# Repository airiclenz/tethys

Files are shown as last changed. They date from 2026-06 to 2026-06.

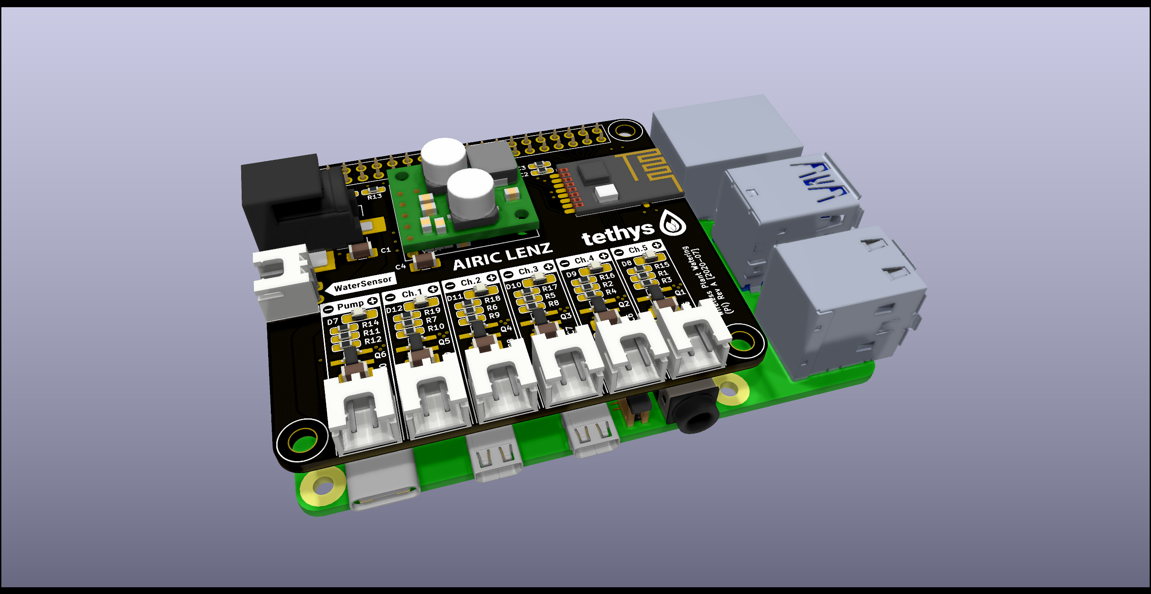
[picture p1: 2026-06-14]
graphics/renders/WaterPlant Pi with PaspPi Render.png

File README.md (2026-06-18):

<div align="center">
Tethys logo

**A self-hosted, multi-channel automatic plant-watering system.**
</div>

Battery-powered wireless soil-moisture sensors report to a Raspberry Pi master
over a 2.4 GHz nRF24 radio link. The master decides when to water, drives the
pumps/valves, and serves a real-time web dashboard — all on your own LAN, no
cloud.

## Part 1 — What Tethys is and how to use it

### The big picture

Tethys has two kinds of hardware:

1. **Sensor nodes** (one per plant/pot, up to 5) — a battery-powered ATtiny84
   board with a capacitive soil-moisture probe and an nRF24L01+ radio. Each node
   sleeps almost all the time, wakes on a configurable interval, measures soil
   moisture and battery voltage, transmits a reading, and goes back to sleep.
   Designed to run for months on a single charge (~9 µA while sleeping).

2. **The master** — a Raspberry Pi with a custom HAT carrying the matching
   nRF24L01+ radio plus pump/valve driver outputs. The master listens for sensor
   readings, stores them, and when a channel's soil drops below its trigger
   threshold it runs that channel's pump (or opens its valve) for a configured
   duration. It also serves the web UI you use to configure and monitor
   everything.

```
   ┌─────────────┐   nRF24 2.4GHz      ┌──────────────────────────────────┐
   │ Sensor node │  (250kbps, 8-byte   │         Raspberry Pi master      │
   │  ATtiny84   │   versioned frames) │                                  │
   │  + moisture │ ◄──── reading ────► │  core daemon ─► pump/valve GPIO  │
   │  + nRF24    │      config ◄────   │              │                   │
   │  (battery)  │                     │  Django API (SQLite) ◄─► web UI  │
   └─────────────┘                     └──────────────┬───────────────────┘
        × up to 5                                     │  HTTP / WebSocket
                                                      ▼
                                              Your browser / phone
```

Each **channel** (1..5) pairs one sensor node with one pump or valve output.
A channel knows its soil-moisture trigger %, its pump run duration, and how
often its sensor should measure.

### Repository layout

```
tethys/
├── code/
│   ├── master/            # Everything that runs on the Raspberry Pi
│   │   ├── core/          # The watering daemon (radio + pump control + action engine)
│   │   ├── api/           # Django REST API (the system's database + state)
│   │   ├── web/           # Django + Channels dashboard (browser UI)
│   │   ├── camera/        # Optional on-demand webcam snapshot service (USB/V4L2)
│   │   ├── watchdog/      # Daily service-restart / log-vacuum job
│   │   ├── globals/       # Shared config + git-ignored secrets
│   │   └── install/       # install.sh, systemd units, nginx configs
│   └── sensor/            # Arduino/PlatformIO firmware for the sensor nodes (the "wpw" project)
├── hardware/              # KiCad schematics + Gerbers for the Pi HAT and the sensor PCB
├── graphics/              # Logos, hardware labels, web-UI assets, renders
└── docs/                  # Audits, protocol review, hardening notes, handoffs
```

### Hardware

**Master — Raspberry Pi + "WaterPlant Pi" HAT** (`hardware/rpi hat/`).
GPIO assignments live in [`code/master/core/hardware.py`](code/master/core/hardware.py):

| Function | BCM pin(s) | Notes |
|---|---|---|
| Channel outputs | `16, 19, 20, 26, 21`  | One per channel; `CHANNEL_COUNT = 5` |
| Shared pump pin | `6` | Energised together with a channel in **valve** mode |
| Water-level sensor| `4` | |
| nRF24 CE / CSN / IRQ | `22 / 0 / 17` | SPI radio |
| Status LED / Fan  | `14 / 15` | |

A channel of type **pump** drives its own pin directly. A channel of type
**valve** drives its pin *and* the shared `PUMP` pin (one pump pushing water
through whichever valves are open); the pump pin is reference-counted so it
only drops once the last valve closes.

**Sensor node — "Sensor" PCB** (`hardware/sensor/`), firmware in `code/sensor/`:

- **MCU:** ATmega/ATtiny84 @ 8 MHz (PlatformIO `TX` build), deep-sleep
  `SLEEP_MODE_PWR_DOWN`, woken by the 8-second watchdog timer.
- **Radio:** nRF24L01+ on CE=8 / CSN=9, 250 kbps, CRC-8, auto-ACK.
- **Moisture:** capacitive probe excited by a ~500 kHz square wave (Timer0 on
  `PB2`), read on ADC `PA3`; calibration min/max stored in EEPROM.
- **Battery:** monitored on `A7` against the internal 1.1 V reference; below
  **3.2 V** the node sends a battery-alert frame instead of a normal reading.

### Install (on the Raspberry Pi)

```bash
sudo apt install git -y
git clone https://github.com/airiclenz/tethys.git tethys
cd tethys/code/master/install
./install.sh
```

The installer updates the OS, creates a Python venv, installs Redis + nginx,
runs the Django migrations, registers the systemd services, enables SPI, and
**reboots** (re-run `./install.sh --rebooted=true` afterward if you decline the
auto-reboot). On first run it generates a random **API key** into the
git-ignored `code/master/globals/secrets.py` and **prints it** — copy it.

Useful flags:
- `--debug=true` — developer install (also installs the TypeScript toolchain).
- `--allowed-hosts=tethys.<tailnet>.ts.net` — extra `ALLOWED_HOSTS` for remote
  (VPN) access. Alternatively (and preferred per-install), list the name in the
  git-ignored `code/master/globals/allowed_hosts.py` (copy `allowed_hosts.example.py`)
  — no reinstall needed, just restart the services. See
  [`docs/remote-access-hardening.md`](docs/remote-access-hardening.md).

After it's up: open `http://<pi-host>/` in a browser → **Settings** (top menu) →
paste the API key → Save. The key gates **every** request (reads included; only
the CORS `OPTIONS` preflight is exempt), so the dashboard stays blank until it's
set. If a page can't authenticate (missing or wrong key), a warning banner
appears under the header with a link straight to Settings.

### Daily use

- **Sensor Readings page** (`/`) — per-channel reading history: two trend charts
  (moisture % and battery voltage over time) sit above a sortable table of the
  individual readings.
- **Channels page** (`/channels/`) — live moisture %, battery, last action per
  channel; enable a channel, set its nickname, type (pump/valve), pump duration,
  and the moisture trigger %; manually test a pump.
- **Schedules page** (`/schedules/`) — define **silent phases** (quiet hours):
  weekday + start time + duration windows during which *all* automatic watering
  is suppressed (e.g. overnight). The header shows a sleep icon while a silent
  phase is active.
- **Webcam page** (`/webcam/`) — *optional* live view from a USB camera. Off by
  default; flip **Enable** to refresh a snapshot every few seconds. Live-view
  only — nothing is recorded, and the camera releases automatically when you
  leave the tab or after an idle timeout. See *Webcam* below.
- **Order 66** (top menu) — recovery action for when a service or the Pi itself
  gets wedged: confirm the popup and the Pi performs a graceful reboot (back in
  ~1 minute). Gated by the API key, like pump control.
- The dashboard updates live over a WebSocket; no manual refresh needed.

### Webcam (optional)

Tethys can show a live webcam view on its own **Webcam** tab — handy for checking
on plants — but it ships **off** and only captures **on demand**:

- **USB camera (V4L2).** Plug in any UVC webcam; the service grabs JPEG snapshots
  with `v4l2-ctl` (no extra Python dependency). A Pi Camera Module (CSI) is not
  wired up yet — the capture code keeps a seam (`camera/captureBackend.py`) for
  adding it as one new class.
- **Snapshot-only, nothing recorded.** The tab fetches a fresh JPEG every few
  seconds (an authenticated `fetch`, gated by the same API key as everything
  else). There is no video stream and no storage — purely a live view.
- **Pick the size, view it full-screen.** A dropdown lists the resolutions the
  camera itself reports (so it isn't tied to one model), and the live frame can be
  expanded to fill the screen — both handy on a phone. The choice is per-session
  only; nothing is saved.
- **Focus & zoom sliders.** A plant sits at a fixed distance, so autofocus just
  hunts. The tab offers focus and zoom as sliders whose ranges are read from the
  camera itself — and a slider is disabled when the camera doesn't support that
  control. Setting focus pins it (no more hunting). Your pick is remembered in the
  browser; `CAPTURE_FOCUS` / `CAPTURE_ZOOM` in `camera/config.py` set the
  defaults a fresh browser starts from.
- **Fail-closed + auto-off.** The service boots disabled (a snapshot while off
  returns `409`). It auto-releases the camera after a short idle window and
  enforces a hard maximum on-time, mirroring the pump's auto-off safety — so the
  camera can never be left on by accident.
- **Least privilege.** `tethys-camera` runs as the normal app user (no root,
  unlike `tethys-core`), with only the `video` group added so it can open the
  `root:video` `/dev/video*` nodes. The installer adds the user to that group and
  installs `v4l-utils`.

### Updating / operating

From `code/master/install/`:
- `./installServices.sh` — re-deploy the systemd services from the current code.
- `./services-restart.sh`, `./services-stop.sh`, `./services-clearLogs.sh`.
- `./deploy-static.sh` — rebuild the frontend TypeScript and publish it to nginx.

The six services: `tethys-core`, `tethys-api`, `tethys-web`, `daphne`,
`tethys-watchdog` (restarts core+api+camera nightly at 01:00 and vacuums the
journal), and `tethys-camera` (the optional on-demand webcam, off by default).

### Firmware (sensor nodes)

Built with [PlatformIO](https://platformio.org/) from `code/sensor/`. Before
building, set the node identity in [`code/sensor/include/wpw_Config.h`](code/sensor/include/wpw_Config.h):
`SENSOR_NUMBER` (1–5). Flash with:

```bash
cd code/sensor
pio run -t program -e tethys-sensor     # via an AVR ISP programmer
```

> ⚠️ **The master and every sensor must be flashed together.** The wire format
> is versioned and fixed-size; a node on mismatched firmware fails the version
> check and goes silent (cleanly — it never corrupts data). See the
> *Known limitations / coordinated flash* note in [`CHANGELOG.md`](CHANGELOG.md).

### Sensor node LED — calibration & status blinks

A sensor node has no screen; its single onboard LED is how it talks to you.
Patterns are produced by `DoSimpleBlink(onMs, offMs)` and `DoSoftPulse(ms)`
([`code/sensor/src/wpw_Blinker.cpp`](code/sensor/src/wpw_Blinker.cpp); the soft
pulse is a software-PWM glow, since the LED pin has no free hardware PWM).

**How calibration works.** Calibration maps the probe's raw reading onto a
0–100 % moisture scale, and it is **two-point**: the node captures one reading in
a *wet* condition and one in a *dry* condition, then stores the lower value as
`MinimumValue` (wettest) and the higher as `MaximumValue` (driest) in EEPROM
(`Calibrate()` in [`code/sensor/src/wpw_Sensor.cpp`](code/sensor/src/wpw_Sensor.cpp)).
Later readings become `100 − map(raw, min, max, 0, 100)` %.

1. Trigger it from the web UI — set the channel's **calibrate** flag
   (`sensorTriggerCalibration`), then **power-cycle or reset the node**.
   Calibration runs only as part of the **boot-time** config exchange (the full
   `GETCONFIG` in `setup()`) — *not* on a normal measurement wake. A running node
   re-pulls its config periodically (see *Periodic config pull* below), but those
   pulls are deliberately **settings-only**: they carry measure-frequency /
   TX-power but never the calibration trigger, so they can't run calibration
   mid-life. The master delivers the trigger once and immediately clears the flag
   (`core/radio.py`), so if you set the flag while the node is already running,
   nothing happens until you reset it. (This is the usual reason a calibration
   "didn't start".)
2. The node then takes **two** measurements, each announced by the *calibration
   countdown* below (slow blinks → fast blinks → one long blink → it measures
   while the LED is off). Put the probe in one condition for the first capture
   and the other condition for the second.
3. **Order doesn't matter** — the firmware sorts the two readings into min/max.
   What matters is that the two conditions are genuinely different: if the two
   readings are too close, the calibration is **rejected** and the previous
   values are kept (signalled by the long 2 s blink).

**First reading after boot.** On every boot — including right after calibration —
the node waits ~1 minute (`STARTUP_SETTLE_SECONDS`, default 60, in
[`wpw_Config.h`](code/sensor/include/wpw_Config.h)) before taking and transmitting
its first reading. It *sleeps* through the wait (you'll see the heartbeat flash
each ~9 s), so it costs almost no power. Put the probe in its final monitoring
position before this window ends — the first reported value reflects wherever the
probe is at that moment, **not** the calibration captures.

**Periodic config pull.** A running node re-pulls its config so web-UI changes
(measure frequency, transmission power) reach it without a power-cycle. The cadence
is `PULL_CONFIG_CYCLE_SECONDS` in [`wpw_Config.h`](code/sensor/include/wpw_Config.h)
(default `3600` = 1 h; **`0` disables it** for maximum battery saving). To stay
gentle on the battery the pull **rides an existing measurement wake** — the radio
is already powered up, so it adds no extra power-up, and the master answers from
its warm `ConfigCache` so the listen window is usually a few milliseconds. The pull
therefore happens on the first measurement at/after the cycle has elapsed since the
last pull. These pulls are **silent** (no LED) and **settings-only** — they never
carry or clear the calibration trigger (calibration stays boot-only; see above).

The patterns, all on the sensor (TX) node LED:

| Event | Blink pattern | Meaning |
|---|---|---|
| **Power-on / node ID** | `N` slow blinks (150 ms on, 300 ms off), where `N` = `SENSOR_NUMBER` | Node booted and is powered; the count identifies which node it is (1–5). |
| **Config received** | a soft ~2 s glow (brightness ramps up then down) | The master answered the config request (at boot) and the settings were applied. |
| **No master reply** | two short flashes (15 ms) | Config request timed out (no answer within 500 ms); the node falls back to the settings stored in EEPROM. |
| **Config rejected** | three short flashes (15 ms) | The master replied but the frame failed the protocol-version / type check. |
| **Settings saved** | accelerating ramp — 150 → 100 → 75 → 50 → 25 → 15 ms — then one long 300 ms flash (ramps *up* to a strong finish) | New settings differed from EEPROM and were written. |
| **Settings unchanged** | decelerating ramp — 15 → 25 → 50 → 75 → 100 → 150 ms — fading out with no final flash (the mirror of *saved*) | Config was checked but nothing changed, so nothing was written. |
| **Heartbeat** | one very short flash (5 ms) each wake (~every 9 s) | Normal sleep/measure loop tick — the node is alive. |
| **Transmit failed** | four short flashes (15 ms) | The radio send failed; the node backs off (~15 min) before retrying. Part of the short-flash radio-error family, counted: 2 = no reply, 3 = bad frame, 4 = send failed (a *successful* config exchange is the soft glow above instead). |
| **Calibration countdown** | 10 slow blinks (300 ms) → 20 fast blinks (100 ms) → one long blink (1 s) → LED off while it measures | Counts down to a calibration capture. Runs **twice**, once per measurement point. |
| **Calibration rejected** | one very long flash (2 s) | The two calibration readings were too close together; calibration was discarded and the previous values kept. |

---

## Part 2 — Orientation for a contributor or coding agent

This half is the lightweight `CLAUDE.md`: the runtime topology, the invariants
that are easy to break, and where to look. Read it before changing anything on
the master.

### Process & port map

Everything runs on the Pi as systemd services (units in
`code/master/install/assets/*.service`, nginx in `*.nginx`):

| Service | Process | Binds | Reached via |
|---|---|---|---|
| `tethys-core` | `core/tethys_core.py` (asyncio) | — (GPIO/radio) | n/a |
| `tethys-api` | gunicorn → `tethys_api.wsgi` | `localhost:5001` | nginx **:5000** |
| `tethys-web` | gunicorn → `tethys_web.wsgi` | `localhost:8000` | nginx **:80** `/` |
| `daphne` | ASGI → `tethys_web.asgi` | `0.0.0.0:8001` | nginx **:80** `/ws/`|
| `tethys-watchdog` | `watchdog/tethys_watchdog.py` | — | nightly restart |
| `tethys-camera` | `camera/tethys_camera.py` (stdlib HTTP) | `127.0.0.1:8002` | nginx **:80** `/camera/` |
| redis-server | Channels layer for daphne | `localhost:6379` | — |

**The API is the single source of truth.** Both the core daemon and the web
backend treat it as the database boundary and reach it at `http://localhost:5000/api/`
(nginx → gunicorn:5001). It is Django REST Framework over **SQLite**
(`api/db.sqlite3`).

### Data flow (one reading → one watering)

1. A sensor wakes, measures, and transmits a 7-byte frame on its pipe.
2. `core/radio.py` (`checkRadioInbox` → `handlePayload`) drains the RX FIFO,
   validates each frame via `core/protocol.py`, and `POST`s the reading to
   `sensorData/`. On success it sets that channel's flag in
   `core/config.py::FlagHandler.channelFlags`.
3. `core/actionEngine.py::handleActions` (called each core-loop pass) checks the
   **silent phase** first (fail-closed — see below), then for each flagged
   channel pulls `channelSummary/<n>` and, if `moisture <= trigger` and the
   channel is enabled, calls `pumpController.run_pump(...)`.
4. `core/pumpController.py` energises the line, arms a `threading.Timer`
   auto-off, and on completion writes an `actionLog/` entry — all non-blocking,
   so the radio keeps listening while a pump runs.
5. The web UI sees the change: `web/tethys_web/jobs.py` polls the API every 10 s
   (`/lastUpdate/`, `/channelSummary/`, `/schedule/`, `/silentPhaseStatus/`) and,
   on a change, broadcasts to all browsers over the `/ws/tethys/` WebSocket
   (`web/tethys_web/consumers.py`).

A **manual *Test Channel* tap** uses the same hardware path, not a separate one:
the API enqueues a `ManualCommand` (it never drives GPIO), the core drains it each
loop pass and runs it through the same `pumpController` (rejecting an activate when
another channel is already running), and writes the outcome back for the UI to
poll. This is what keeps the one-channel power limit holding for manual control —
see *Invariants* below.

When a sensor asks for its config (`GETCONFIG`), the master answers from an
in-memory `ConfigCache` (warmed out-of-band by `Radio.refreshConfigCache`), never
with a blocking HTTP call inside the sensor's short listen window. A running node's
periodic, settings-only pull (`GETCONFIG_PERIODIC`) is answered the same way but
with the calibration trigger stripped and never cleared.

### Invariants — break these and something physical or silent goes wrong

- **Pump safety.** Every "pump on" is clamped to `MAX_PUMP_SECONDS = 300` and has
  a guaranteed off (timer + `try/finally`). The controller drives all lines LOW
  on construction (fail-safe boot) and on `SIGTERM`/`atexit`. Never reintroduce a
  watering path that bypasses `pumpController`. `make_controller()` is the *only*
  place `lgpio` is bound; all hardware goes through the `GpioAdapter` seam so the
  logic is testable without a Pi.
- **One channel at a time (power limit).** `pumpController` is the *single owner*
  of the watering GPIO. Both automatic watering and the web UI's manual *Test
  Channel* taps go through it — the latter via the `ManualCommand` queue the core
  drains each loop pass — so its `max_concurrent = 1` guard holds the invariant
  that **at most one channel (plus the shared pump pin) is ever energised**, which
  protects the power supply. A manual activate that arrives while another channel
  is running is *rejected*, not run. The API process never drives GPIO itself.
- **Silent phase is fail-closed.** If the API is unreachable, `isInSilentPhase()`
  returns `None` and `actionEngine` **skips watering** for that pass — it must
  never water on unknown state. The window math lives in
  `api/tethys_api/silentphase.py` (stdlib-only, unit-tested independently of
  Django).
- **Timezones.** `globals/config.py::TIME_ZONE` (`Europe/Stockholm`) is the
  single deployment/display zone, shared by `core` and `web`. The **Django API
  deliberately keeps `TIME_ZONE = 'UTC'` as its storage zone** — schedule start
  times are wall-clock times-of-day stored on a placeholder date; the deployment
  zone is applied only at silent-phase evaluation. Don't "fix" the API to local
  time. (See the silent-phase fixes in `CHANGELOG.md` for why.)
- **Wire protocol is versioned and fixed-size.** `core/protocol.py` and
  `sensor/include/wpw_RXTX.h` / `wpw_Config.h` must stay byte-for-byte in sync:
  `PROTOCOL_VERSION = 1`, `PAYLOAD_SIZE = 8`, structs `<BBBf>` (sensor→master, 7 B)
  and `<BBHB?>` (master→sensor, 6 B). Bump `PROTOCOL_VERSION` on *any* layout
  change — and re-flash everything (no backward compat). Adding a new *message
  type* (the type byte, e.g. `DATATYPE_CMD_GETCONFIG_PERIODIC = 8`) is **not** a
  layout change, so it does not bump the version; keep the type constants in sync
  on both ends. An un-updated peer ignores an unknown type (the sensor's periodic
  pull just times out and retries), so mixed versions degrade gracefully.
- **Pipe 0 is reserved.** Channels map 1:1 onto nRF24 reading pipes 1..N; pipe 0
  is the ACK/writing address. This caps the link at 5 sensors. See
  `protocol.pipe_for_channel`.
- **`CHANNEL_COUNT` is the single source of truth** (`= len(Pins.CHANNELS) = 5`).
  The DB/radio reference 6 channels historically; a 6th needs a physical GPIO pin
  first. Don't hardcode channel counts.
- **Secrets.** `globals/secrets.py` (git-ignored) holds `TETHYS_API_KEY`,
  `API_SECRET_KEY`, `WEB_SECRET_KEY`, and is read by *both* the Django apps and
  the non-Django core. Template: `globals/secrets.example.py`. Every API request
  needs `X-API-Key` (reads included; only CORS `OPTIONS` is exempt) — see
  `api/tethys_api/permissions.py::ApiKeyRequired`.

### Auth posture

A single shared API key gates **all** requests, compared constant-time,
fail-closed. The core (`apiInterface.py`, `radio.py`) and the web backend
(`jobs.py`, `tools.py`) send it server-side; the browser stores it in
`localStorage` and `common.ts` injects it into every fetch. Transport is plain
HTTP on the LAN — for remote access, front it with a VPN overlay (Tailscale/
WireGuard), not an open port. See [`docs/remote-access-hardening.md`](docs/remote-access-hardening.md).

### Data model (Django, `api/tethys_api/models.py`)

- **Channel** (`number` PK) — `enabled`, `nickName`, `channelType` (pump/valve),
  `actionTriggerPercent`, `pumpDurationSeconds`, `sensorMeasureFrequencyMinutes`,
  `sensorTriggerCalibration`, `sensorTransmissionPowerLevel`.
- **SensorData** — `channel` FK, `moisturePercent`, `batteryVoltage`, `timestamp`.
- **ActionLog** — `channel` FK, `actionType`, `startTime`, `endTime`.
- **Schedule** — `weekday`, `scheduleType` (`silent`), `startTime` (UTC wall-clock),
  `durationMinutes`, `enabled`.
- **ManualCommand** — `channel` FK, `action` (activate/deactivate), `status`,
  `message`, `requestedAt`, `processedAt`. The web UI enqueues a manual *Test
  Channel* tap here; the core drains it through `pumpController` (the API never
  drives GPIO) and reports the outcome back for the UI to poll.
- Lookup tables: `ChannelType`, `ActionType`, `ScheduleType`, `TransmissionPowerLevel`.
- `channelSummary/<n>` is the denormalized read both the core and UI consume
  (channel config + latest sensor reading + counts).

### Tests

**Backend (core + API)** — pure Python, no Pi/hardware needed:

```bash
cd code/master
pip install -r install/python-requirements-dev.txt   # pytest, dev-only
pytest                                                # pytest.ini sets paths
```

Covers the parts that gate physical action or silent failure: `core/tests/`
(pump controller, GPIO adapter, protocol framing, action engine, manual-command
queue) and `api/tethys_api/tests/` (API-key permission, silent-phase window math,
`LAST_DATA_UPDATE` wiring, manual-command lifecycle). All run without `lgpio`/`pyrf24`/a Pi, thanks to the
GPIO and protocol seams. **Add tests behind those seams when you touch the
watering, radio-framing, or silent-phase paths.**

The camera service has its own pure-Python suite (`camera/tests/`: the
fail-closed snapshot gate, idle / max-on auto-off, and the X-API-Key check, via
`FakeSnapshotBackend`). It is not in the default `testpaths`, so run it
explicitly: `pytest camera/tests`.

**Web UI (Playwright)** — browser-driven regression tests for the channels UI:

```bash
cd code/master/web
pip install -r requirements-dev.txt
playwright install --with-deps chromium   # downloads Chromium + apt libs (needs sudo)
pytest
```

These drive a headless Chromium against a throwaway Django live server, exercising
the real compiled JavaScript (`conftest.py` compiles `static/ts` → `static/js`
first), so they catch DOM/click-handler bugs the Python suites can't. See
[`web/tests/README.md`](code/master/web/tests/README.md) for what's covered and how
it works. A developer install (`install.sh --debug=true`) installs all of the above
automatically.

### Frontend build

TypeScript sources in `web/static/ts/` compile to `web/static/js/` via
`compile.sh` (`tsc`) / `compileAutomatically.sh` (watch). The build is strict
(`strict: true` in `tsconfig.json`) and `tsc -p tsconfig.json` compiles cleanly.
Use `install/deploy-static.sh` to compile + publish to the nginx static dir. The
compiled `web/static/js/` is git-ignored — it is rebuilt from the `.ts` sources on
deploy and before the UI tests, so the TypeScript is the single source of truth.

> ⚠️ **Editing the frontend? Change the `.ts` files in `web/static/ts/`, never
> `web/static/js/` directly.** The `.js` folder is generated output (git-ignored)
> and is overwritten on every `tsc` run / deploy, so any hand-edits to the `.js`
> are silently lost. Tip: `git check-ignore <path>` will tell you if a file is a
> build artifact before you touch it.

### Known limitations / deferred (see `CHANGELOG.md` + `docs/`)

- Low-battery flag is logged but not persisted (no `SensorData` column yet).
- Webcam is live-view only — no recording / clip storage, snapshot download, or
  multiple cameras; the CSI/`picamera2` backend is deferred (seam left in
  `camera/captureBackend.py`).

### Where the design rationale lives

`docs/audits/` (code audit, architecture review, protocol review) and
`docs/handoffs/` capture *why* the current shape exists — the pump-safety module,
the API-key lockdown, the protocol hardening, and the silent-phase timezone fixes.
`CHANGELOG.md` is the readable summary of each. Start there before reworking any
of the invariants above.

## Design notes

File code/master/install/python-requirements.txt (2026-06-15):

rpi-lgpio
gpiozero
pyrf24
django
djangorestframework
drf-spectacular
django-filter
django-cors-headers 
channels
channels-redis
daphne
requests
tzlocal
numpy
colorama
gunicorn
schedule
simple-pid

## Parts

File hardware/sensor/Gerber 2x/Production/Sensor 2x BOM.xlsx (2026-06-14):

Comment | Designator | Footprint | LCSC
4.7uF | C13,C14,C23,C24 | Airic_Lenz:Device_0603_Handsoldering | C19666
0.1u | C15,C25 | Airic_Lenz:Device_0603_Handsoldering | C14663
1u | C16,C11,C12,C17,C26,C21,C22,C27 | Airic_Lenz:Device_0603_Handsoldering | C15849
LED | D13,D11,D23,D21 | Airic_Lenz:LED_0805_Handsoldering | C84256
D_Small | D14,D12,D24,D22 | Airic_Lenz:Diode_0603_Handsoldering | C283259
JK-SMD0603-005 | F11,F21 | Airic_Lenz:Device_0603_Handsoldering | C70045
2k | R13,R11,R23,R21 | Airic_Lenz:Device_0603_Handsoldering | C22975
10k | R14,R15,R12,R24,R25,R22 | Airic_Lenz:Device_0603_Handsoldering | C25804
510k | R16,R26 | Airic_Lenz:Device_0603_Handsoldering | C23192
MCP1700-3002E / XC6206P302 | U11,U21 | Package_TO_SOT_SMD:SOT-23_Handsoldering | C9972
MCP73831-2-OT | U12,U22 | Package_TO_SOT_SMD:SOT-23-5_HandSoldering | C424093
ATtiny84-20SSU | U13,U23 | Package_SO:SOIC-14_3.9x8.7mm_P1.27mm | C144333

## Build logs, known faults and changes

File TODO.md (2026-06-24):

# TODO

items from this list tjhat have been implemented are moved to the file `CHANGELOG.md`.

- persist the low-battery flag: `SensorData` has no battery-alert column, so the
  sensor's `DATATYPE_SENSORDATA_BATTERYALERT` is currently only logged (the
  reading itself is saved). Add a field + migration to store it. See
  `docs/audits/2026-06-13 - ProtocolReview.md` (P-01).

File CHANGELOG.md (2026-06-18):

# Changelog

All notable changes to Tethys are documented here.

The format is based on [Keep a Changelog](https://keepachangelog.com/en/1.1.0/),
and the project aims to follow [Semantic Versioning](https://semver.org/spec/v2.0.0.html).
Current released version: **3.0.0** (`code/master/globals/config.py`).

---

## [Unreleased]

### Webcam: optional on-demand snapshot tab

> (2026-06-18). Tethys had no camera support. This adds an **optional** live
> webcam view on its own tab, **off by default** and capturing **on demand** —
> not a constantly-running stream. It slots in as one more isolated systemd
> service (`tethys-camera`), deliberately separate from the single-worker API
> (which must never block on a ~0.3–1 s camera grab) and well away from the
> safety-critical pump daemon. Capture is snapshot-only (a fresh JPEG every few
> seconds via an authenticated `fetch`), so nothing is recorded and the API key
> never lands in a URL. Safety mirrors the pump's auto-off philosophy: the
> service is **fail-closed** (a snapshot while disabled returns `409`),
> auto-releases the device after an idle window, and enforces a hard max-on
> ceiling so the camera can never be left on indefinitely.

#### Added
- **`camera/`** — a new standalone service: **`tethys_camera.py`** (stdlib
  `ThreadingHTTPServer` on `127.0.0.1:8002`; a constant-time `X-API-Key` gate
  reusing the API's trust model; `start` / `stop` / `snapshot` / `status`
  routes), **`cameraController.py`** (the enabled state machine + idle / max-on
  `threading.Timer` auto-off), and **`captureBackend.py`** (a `SnapshotBackend`
  seam: `V4l2UsbBackend` via `v4l2-ctl` with capability-based device selection, a
  `Picamera2Backend` stub for a future CSI swap, and `FakeSnapshotBackend` for
  tests).
- **Web UI** — a new **Webcam** tab (**`web/templates/index-webcam.html`**,
  **`web/static/ts/webcam.ts`**): an Enable flip switch that arms the service and
  refreshes a JPEG every few seconds via blob object URLs (revoking the previous
  one each tick), auto-stopping when the page is closed or left. Wired into
  `layout.html`, `urls.py` / `views.py`, and `common.ts` (location + active-menu).
- **Deployment** — **`install/assets/tethys-camera.service`** (runs unprivileged
  with `SupplementaryGroups=video`), an nginx `/camera/` location (IPv4-pinned),
  `install.sh` adds the app user to the `video` group and installs `v4l-utils`,
  and the service joins `installServices.sh`, the restart / stop / clear-logs
  scripts, and the watchdog's nightly restart.
- Tests: **`camera/tests/`** — the fail-closed snapshot gate, idle and max-on
  auto-off, and the auth check, all with `FakeSnapshotBackend` (no hardware).

### Webcam: device-derived capture resolution + full-screen view

> (2026-06-18). The Webcam tab captured at a fixed 1280×720 and had no
> full-screen view. Resolution is now **selectable** from a dropdown the client
> fills from the camera itself (so it isn't hardcoded to one model), and the live
> frame can be viewed **full-screen** — built for phone-width viewports. Both are
> in-session only; nothing is persisted or recorded.

#### Added
- **Selectable resolution** — `cameraController.status()` now reports the camera's
  advertised MJPG sizes (**`captureBackend.V4l2UsbBackend.supported_resolutions()`**,
  parsed from `v4l2-ctl --list-formats-ext`, **fail-soft** so `status()` never
  throws) plus the default size. The snapshot request carries `?w=&h=`, validated
  in the pure router (**`tethys_camera._snapshot`**) with a new **400** for a
  malformed or unsupported size. Capture stays one-shot — resolution is a
  per-request parameter, no restart.
- **Full-screen view** — a control toggles a CSS overlay class on the live `<img>`
  (**`.camera-fullscreen`**); tap or Escape exits. A CSS overlay (not the
  Fullscreen API) because iOS Safari can't fullscreen an `<img>`; the polling loop
  keeps refreshing the same element underneath.

### Webcam: focus + zoom sliders, read from the camera

> (2026-06-18). A plant camera points at a fixed distance, so the camera's
> default continuous autofocus only adds hunting and "breathing" between
> otherwise-identical snapshots. The Webcam tab now offers **focus** and **zoom**
> as live sliders, with each slider's range read **from the camera itself** and
> **disabled when the camera doesn't expose that control** — so it adapts to any
> USB camera instead of being hardcoded, and is adjustable from a phone in the
> field (no config edit, the original ask). Setting focus pins it (disabling
> continuous AF), killing the breathing.

#### Added
- **Device-derived controls** — `cameraController.status()` now reports the
  focus/zoom ranges the camera advertises
  (**`captureBackend.V4l2UsbBackend.supported_controls()`**, parsed from
  `v4l2-ctl --list-ctrls`, **fail-soft** so `status()` never throws), each as
  `{min, max, step, value}` with `value` seeded from `config.CAPTURE_FOCUS` /
  `CAPTURE_ZOOM` when in range. Only controls the camera exposes are reported.
- **Per-request application** — the snapshot request carries `?focus=&zoom=`
  (validated in the pure router **`tethys_camera._snapshot`** against the
  camera's ranges, a new **400** for out-of-range/non-integer). Pinning focus
  handles two camera quirks verified on the C200: continuous AF is switched off
  in its **own committed `v4l2-ctl` invocation** before the grab (`focus_absolute`
  is `INACTIVE` while AF owns the lens; the camera keeps AF-off across the reopen,
  and a separate call is robust where a combined cluster set isn't); and because
  the camera **resets `focus_absolute` when a stream stops** and its focus motor
  **only travels while streaming**, a focused grab discards
  **`CAPTURE_FOCUS_SETTLE_SKIP_FRAMES`** (≈1 s) so the lens reaches the requested
  position before the kept frame — without it the lens is caught mid-travel and
  looks like AF is still hunting. Zoom is digital (instant, not reset on stream
  stop) so it rides the grab's own `--set-ctrl`. A control the camera lacks is
  never emitted, so a value can't wedge the grab.
- **UI sliders** — focus/zoom `<input type="range">`s in the Webcam tab populate
  from `status.controls` and **disable** for unsupported controls; a pick is
  remembered per-device in `localStorage` and re-fetches at once. `CAPTURE_FOCUS`
  / `CAPTURE_ZOOM` remain as the server-side seed defaults a fresh browser sees.

### Webcam: keep the camera running while the tab is hidden

> (2026-06-18). The Webcam tab released the camera the moment its tab went hidden
> (`visibilitychange`), so a brief switch to another app killed the live view —
> and that stop `fetch`, fired as the page was being frozen, surfaced in Safari as
> a misleading `Fetch API cannot load … due to access control checks` console
> error (it is same-origin; nothing was actually blocked). The camera now stays
> running across app/tab switches and is released only on a real page-leave or by
> the service's own timeout.

#### Changed
- **`web/static/ts/webcam.ts`** — dropped the `visibilitychange` auto-stop; the
  `pagehide` release now fires only on a real teardown (`event.persisted === false`),
  so an iOS app-switch into the back/forward cache is left running, and a new
  `pageshow` handler re-syncs state when the page is restored from that cache.
- **`camera/config.py`** — `IDLE_TIMEOUT_SECONDS` widened from 15 s to 30 min so a
  backgrounded tab whose polling has paused isn't released early; `MAX_ON_SECONDS`
  (30 min) stays the ceiling, now the effective single timeout.

#### Fixed
- The spurious `access control checks` console error on switching away from the
  Webcam tab (the doomed stop `fetch` is no longer fired on hide).
- The spurious `Snapshot fetch failed: TypeError: Load failed` console error on a
  page reload/navigation: the in-flight snapshot `fetch` the navigation cancels
  now sets a `tearingDown` flag that `tick()`'s `catch` recognises, so it stays
  quiet instead of logging — a genuine mid-session drop still reports.

### Webcam: live frame counter

> (2026-06-18). A small **"Frame N"** readout above the live view, incrementing as
> each snapshot lands, so it's visible at a glance that the view is actually
> refreshing (and how many frames a session has shown).

#### Added
- **`web/templates/index-webcam.html`** / **`web/static/ts/webcam.ts`** — a
  `#idCameraFrameCount` span beside the Full screen control: reset on each enable,
  incremented per rendered frame in `tick()`, blanked when the camera stops (so it
  rides every existing auto-off path for free).

### Watering: enforce "one channel at a time" for manual control, not just automatic

> (2026-06-17). Automatic watering already serialised — `pumpController` runs one
> channel at a time (`max_concurrent = 1`). But the web UI's manual "Test Channel"
> toggle drove GPIO directly from the Django API process, bypassing the controller:
> two manual taps, or a manual tap during an automatic pump, could energise more
> than one channel at once and overload the power supply. The API and core are
> separate processes (and the API runs 3 gunicorn workers), so no in-memory guard
> could prevent it. Manual taps now flow through the *same* single controller as
> automatic watering, so the one-channel power limit ("max one channel + pump")
> holds at all times. Resolves audit findings **[H-01]** (two GPIO owners /
> swallowed error returns `True`) and the manual-activate half of **[C-02]** (no
> auto-off on a manual activate).

#### Added
- **`api/tethys_api/models.py`** / **`migrations/0004_manualcommand.py`** — a
  `ManualCommand` queue (`action`, `status`, timestamps) the web UI writes and the
  core drains. The API no longer imports any core GPIO module.
- **`api/tethys_api/views.py`** / **`urls.py`** / **`serializers.py`** —
  `channel_single_action` now *enqueues* a command and returns its id; new
  `GET /api/manualCommand/pending` (polled by the core) and
  `GET|PATCH /api/manualCommand/<id>` (UI polls the outcome, core reports it).
- **`core/manualCommands.py`** + **`core/apiInterface.py`** + **`core/tethys_core.py`**
  — the core drains pending commands each loop pass and runs them through
  `pumpController.activate`/`deactivate`. A manual activate while another channel is
  running is **rejected** (the `max_concurrent = 1` guard); a stale request (core
  was down) is **expired**; a manual activate now inherits the 300 s auto-off ceiling.
- **`web/static/ts/channel.ts`** — the Test Channel toggle polls the command's
  outcome and reverts itself (with an "another channel is active" message) when an
  activate is rejected.
- Tests: **`core/tests/test_manual_commands.py`** (accept / reject-when-busy /
  expire / deactivate) and **`api/tethys_api/tests/test_manual_command.py`**
  (enqueue, pending list, result write-back).

#### Removed
- **`core/channel.py`** — the legacy `setOutputState` GPIO path (the second GPIO
  owner, and the one that returned `True` even after a swallowed write error) is
  deleted; all watering GPIO now has a single owner.

### nginx: intermittent 502s / failed `/channels` redirect from IPv6 `localhost` upstreams

> (2026-06-17). Opening Tethys — most visibly over Tailscale — sometimes showed
> an nginx error page instead of redirecting `/` → `/channels`, and live data
> could silently drop. It looked host- or cache-specific ("reload fixes it",
> "works in another browser"), but the root cause was a dual-stack `localhost`
> mismatch with no relation to the hostname, Tailscale, or caching.

#### Fixed
- **`install/assets/tethys-{web,api}.nginx`** — `proxy_pass` targeted the name
  `localhost`, which resolves to both `127.0.0.1` and `[::1]`, while gunicorn
  (web `:8000`, api `:5001`) and daphne (`:8001`) bind IPv4 only. nginx
  round-robined onto `[::1]`, hit `connect() failed (111: Connection refused)`,
  and served its own 502 (the "nginx page") instead of Django's `/ → /channels/`
  redirect — masked intermittently by per-request retries. Pinned all three
  upstreams to `127.0.0.1`. Verified live: zero new `[::1]` failures under load.
  (`assets-localized/` is gitignored and regenerated from these templates.)

### Watchdog: nightly maintenance was a silent no-op (restricted PATH)

> (2026-06-17). The watchdog's 01:00 job — restart `tethys-api`/`tethys-core`
> and vacuum the journal — had been failing every night while logging success.
> The commands never ran, so the services were never actually cycled.

#### Fixed
- **`watchdog/tethys_watchdog.py`** — `restartServices()` called `systemctl`
  and `journalctl` as bare commands through `os.system()`. The systemd unit
  pins `PATH` to the venv bin (`Environment=PATH=…/env_tethys/bin`), so the
  `/bin/sh` that `os.system()` spawns could not resolve either binary
  (`sh: 1: systemctl: not found`). The exit code was ignored and the success
  `print()`s ran unconditionally, so the failure was invisible in the journal.
  Now uses absolute paths (`/usr/bin/systemctl`, `/usr/bin/journalctl`) — the
  same fix as the `/api/reboot/` endpoint — and checks each return code so a
  future failure logs `FAILED` instead of a false success. No unit change
  needed; the restricted `PATH` is sidestepped per-call.

### Web frontend: "Order 66" menu action now reboots the Pi

> (2026-06-17). The "Order 66" menu item opened a confirmation popup whose OK
> button linked to `/shutdown` — a route that never existed, so clicking it just
> 404'd. It is now a real recovery action for when a service or the Pi itself
> gets wedged: it triggers a graceful reboot, gated by the API key like every
> other control action.

#### Added
- **`api/tethys_api/views.py`** / **`api/tethys_api/urls.py`** — new
  `POST /api/reboot/` endpoint. Key-gated by the default `ApiKeyRequired`
  permission (so a bare GET can't trigger it) and POST-only. It runs a
  **graceful** `systemctl reboot` (not `reboot -f`) so core's SIGTERM hook
  (`_shutdownPumps`) drives every valve pin LOW before the power cycle, and
  defers it via a detached shell (`sleep 3 && …`) so the `202` reaches the
  browser before services tear down. Absolute binary paths are used because the
  service's `PATH` is pinned to the venv bin (`Environment=PATH=…`), so bare
  `sh`/`systemctl` would not resolve.
- **`web/static/ts/common.ts`** — `requestReboot()` POSTs to `/api/reboot/` via
  the existing key-attaching `postCall` helper, shows a "rebooting…" notice on
  success, and reuses the `#authBanner` on a 403 (same UX as pump control).
- **`web/templates/layout.html`** — the Order 66 popup OK button now calls
  `tethys.requestReboot()` instead of linking to the dead `/shutdown`; the
  confirmation copy states it reboots the Pi (offline ~1 minute).

#### Removed
- **`web/templates/index-shutdown.html`** — dead template for the never-routed
  `/shutdown` page; the "rebooting…" state is shown client-side in the popup.

### Web frontend: auth-failure banner on page load

> (2026-06-16). Every API request needs an `X-API-Key`; a missing or wrong key
> gets a 403 (`api/tethys_api/permissions.py`), and until the key is pasted into
> Settings the dashboard just sat blank with no explanation. The page now probes
> the API once on load and tells the user when authentication is the problem.

#### Added
- **`web/static/ts/common.ts`** — on page load `afterPageLoad()` runs a one-shot
  `checkApiAuth()` probe against the cheapest endpoint (`GET /api/version/`).
  A 403 shows a non-blocking warning banner; any other result (or a successful
  probe) hides it. `saveApiKeyFromField()` re-probes so the banner clears the
  moment a correct key is saved, without a reload.
- **`web/templates/layout.html`** / **`web/static/css/main.css`** — a dismissible
  `#authBanner` under the site header reading "Authentication failed — the API
  key is missing or invalid", with a link straight to the Settings popup.
- **`web/tests/test_auth_banner_ui.py`** — Playwright regression tests: the
  banner appears when the probe returns 403 and stays hidden when it returns 200
  (the probe is mocked via request interception).

### Channels UI: fix sparse-channel settings crash + click-outside to deselect

> (2026-06-16). Channels are identified by number and may be non-contiguous
> (e.g. 1, 2, 5). The settings code looked a channel up with `channels[number - 1]`,
> assuming a dense array, so clicking channel 5 evaluated `channels[4]` on a
> 3-element array and threw `TypeError: undefined is not an object`, breaking the
> settings panel.

#### Fixed
- **`web/static/ts/channel.ts`** — `getIndexOfchannelWithNumber()` now resolves the
  index via `Array.findIndex(channel => channel.number === number)` instead of
  `number - 1`, so sparse / non-contiguous channel numbers open settings correctly.

#### Added
- Click-outside-to-deselect for the channel list: clicking outside a selected
  channel deselects it and closes its settings.

### Web frontend: Playwright UI test harness + stop committing compiled JS

> (2026-06-16). There were no browser-level tests, so DOM / click-handler
> regressions (like the sparse-channel crash above) slipped through the pure-Python
> suites. Added a pytest + Playwright harness, and stopped committing the compiled
> JavaScript now that it is rebuilt deterministically on deploy and before tests.

#### Added
- `web/tests/` — pytest + Playwright UI regression tests. `test_channels_ui.py`
  covers the sparse-channel settings crash by injecting channels 1/2/5 through the
  page's own render path, clicking channel 5, and asserting the settings panel opens
  with no uncaught error. Supporting files: `web/conftest.py` (compiles `static/ts`
  → `static/js` before tests, mirroring deploy), `web/tethys_web/settings_test.py`
  (serves static from source, no `collectstatic`), `web/pytest.ini`, and
  `web/requirements-dev.txt` (pytest-django, pytest-playwright). See
  `web/tests/README.md`.
- **`install/install.sh`** — a developer install (`--debug=true`) now also installs
  the dev/test tooling into the venv (backend + web dev requirements and
  `playwright install --with-deps chromium`). A production install is unchanged.

#### Changed
- Compiled `web/static/js/` is no longer tracked in git (`.gitignore`); it is
  rebuilt from `static/ts` on deploy (`deploy-static.sh`) and before the UI tests
  (`conftest.py`). The `.ts` sources are the single source of truth.

### Sensor Readings: moisture & battery-voltage trend charts

> (2026-06-15). The Sensor Readings page only listed raw readings in a table, so
> trends over time were hard to see at a glance. It now shows two time-series line
> charts — moisture % and battery voltage — side by side above the table, drawn
> entirely from data the page already loads.

#### Added
- `code/master/web/static/ts/charts.ts` (`tethys.charts`) — renders the moisture
  and battery-voltage line charts for the selected channel from the readings
  `measurements.ts` already fetches. Charts update in place on channel change /
  delete and clear when a channel has no data.
- `code/master/web/static/vendor/chart.umd.min.js` — Chart.js v4.4.6 (UMD),
  self-hosted so the dashboard keeps working offline (no CDN). `installServices.sh`
  and `deploy-static.sh` now publish the `vendor/` folder to `staticcollect`, and
  `layout.html` loads it before the app scripts.

#### Changed
- **`web/templates/index-measurements.html`** — two chart cards (moisture /
  battery voltage) added above the readings table.
- **`web/static/ts/measurements.ts`** — `render()` now also refreshes the charts.
- **`web/static/css/main.css`** — chart card / canvas styling.

### Remote access: nginx catch-all + git-ignored extra `ALLOWED_HOSTS`

> (2026-06-15). Reaching the Pi by a name other than `tethys.local` (e.g. its
> Tailscale name) used to fall through to the stock "Welcome to nginx!" default
> site, and required baking the hostname into the systemd units at install time.
> The web vhost is now the catch-all `default_server` and the host allow-list can
> be set per-install in a git-ignored file with only a service restart.

#### Added
- `code/master/globals/allowed_hosts.py` (git-ignored, with committed
  `allowed_hosts.example.py`) defining `EXTRA_ALLOWED_HOSTS`. Both Django settings
  read it at runtime and append it to `ALLOWED_HOSTS`; the import is non-fatal, so
  an absent file just means no extra hosts. The existing `--allowed-hosts` flag /
  `TETHYS_ALLOWED_HOSTS` env var still work and are unioned in.

#### Changed
- **`install/assets/tethys-web.nginx`** — the web site is now
  `listen 80 default_server` on IPv4 **and** `[::]:80` (dual-stack), so it serves
  Tethys for any Host header / IP.
- **`install/installServices.sh`** — removes the stock nginx default site
  (`/etc/nginx/sites-enabled/default`) so it can't own `default_server` or shadow
  the app.
- Docs (`docs/remote-access-hardening.md`, `README.md`) updated for the file-based
  host list and the catch-all vhost; fixed the remote-access URL to port 80 (the
  `:8000` gunicorn port is loopback-only).

### Remove the legacy Arduino `#ifdef RX` receiver firmware

> (2026-06-14). The firmware in `code/sensor/` used to compile into two roles
> selected by a `#define TX` / `#define RX` switch: the battery sensor node (TX)
> and a standalone Arduino Leonardo receiver/master (RX) with an OLED, buttons,
> and pump/valve outputs. The RX master was superseded by the Raspberry Pi master
> (`code/master/`) and was no longer built or flashed, so its half of every shared
> file was dead weight. The project now builds a **single firmware** — the sensor
> node — with no role macro at all. No behaviour change to the sensor, and the
> wire protocol is untouched (`PROTOCOL_VERSION` stays **1**).

#### Removed
- RX-only modules `wpw_UI`, `wpw_Input`, `wpw_Pumps` (`.cpp` + `.h`), the
  `platformio.ini.RX` build env, and the orphaned `pre-build.py` (it was wired in
  only via the RX build's `extra_scripts`).
- Every `#ifdef RX` block across the shared files (`wpw_RXTX`, `wpw_Sensor`,
  `wpw_Blinker`, `wpw_EEPROM`, `wpw_Config`, `WirelessPlantWatering.cpp`).

#### Changed
- The now-always-true `#ifdef TX` guards and the `#define TX` / `#define RX`
  selector in `wpw_Config.h` are gone; the TX paths are unconditional. The sole
  PlatformIO env is renamed `[env:TX]` → `[env:tethys-sensor]` (now that there is
  only one role): `pio run -e tethys-sensor`.

### Periodic config pull — push config changes to running nodes without a reboot

> (2026-06-14). Previously a sensor only fetched its config at boot
> (`RequestConfiguration()` in `setup()`), so a measure-frequency or TX-power
> change made in the web UI didn't reach a running node until it was manually
> power-cycled. Nodes now re-pull their config on a configurable cycle. The pull
> **rides an existing measurement wake** (the radio is already powered up), so it
> adds no extra radio power-up; the master answers from its warm `ConfigCache`,
> so the listen window is usually a few milliseconds. Set
> `PULL_CONFIG_CYCLE_SECONDS = 0` to disable periodic pulls entirely (the feature
> compiles out — zero cost — for maximum battery saving); the boot-time fetch
> still happens. The existing `GETCONFIG`/`CONFIG` handshake is reused; the wire
> layout is unchanged, so `PROTOCOL_VERSION` stays **1**.
>
> Calibration stays a **boot-only**, user-supervised operation. The periodic pull
> uses a distinct settings-only request (`DATATYPE_CMD_GETCONFIG_PERIODIC = 8`)
> that the master answers with measure-frequency / TX-power only, never carrying
> or clearing the one-shot calibration trigger — so an hourly pull can't silently
> consume a pending calibration request.

#### Added
- **`sensor/include/wpw_Config.h`** — `PULL_CONFIG_CYCLE_SECONDS` (default `3600`,
  `0` = disabled), the re-pull cadence in seconds.
- **`sensor/include/wpw_RXTX.h` + `core/protocol.py`** — new message type
  `DATATYPE_CMD_GETCONFIG_PERIODIC = 8` (sensor → master), kept in sync on both ends.
- **`core/tests/test_radio_sendconfig.py`** — periodic-pull never clears the
  calibration flag and strips the trigger while preserving the real settings.

#### Changed
- **`sensor/src/WirelessPlantWatering.cpp`** — `loop()` re-pulls config on the
  first measurement at/after `PULL_CONFIG_CYCLE_SECONDS` has elapsed (guarded by
  `#if`, so disabling costs nothing); persists changed settings silently.
- **`sensor/src/wpw_RXTX.cpp`** — `RequestConfiguration(bool periodic = false)`:
  the periodic path uses the new opcode, never triggers calibration, and stays
  silent (no LED) to save awake time.
- **`sensor/wpw_EEPROM.{h,cpp}`** — `SaveSettingsToEeprom(bool showFeedback = true)`
  for a silent save from the running loop.
- **`core/radio.py`** — `handlePayload` routes the periodic opcode to
  `sendConfig(channelNo, includeCalibration=False)`, which sends settings only and
  never clears the calibration flag.

### TypeScript strict-mode cleanup (clean `tsc` build)

> (2026-06-14). The frontend `web/static/ts/` sources (one `namespace tethys`)
> compiled with **311 pre-existing type errors** (implicit-any, possibly-null)
> under a `tsc` that defaults `strict` on — surfaced as "compile errors" when
> running `install/deploy-static.sh`. Annotated the types and added null/DOM
> assertions so the build is clean, then enabled `strict` explicitly. The fixes
> are **type-level only** (annotations / `!` / casts): the emitted JavaScript is
> unchanged apart from erased-annotation cosmetics and `tool.ts`'s
> namespace-local `this.pad`/`this.getTimeString` becoming direct calls to the
> same functions. No runtime behavior changed.

#### Changed
- **`web/static/ts/tsconfig.json`** — added `"strict": true` and
  `"forceConsistentCasingInFileNames": true`. `tsc -p tsconfig.json` now reports
  **0 errors** (was 311) and `deploy-static.sh` compiles cleanly.
- **`web/static/ts/*.ts`** (`actions`, `channel`, `common`, `measurements`,
  `schedule`, `templatter`, `tool`, `websocket`) — explicit parameter/variable
  type annotations, non-null assertions on `document.getElementById(...)` and
  `response.body`, selection-state/index vars typed to avoid null-index cascades,
  `Templatter` field definite-assignment (`!`), and `authHeaders()` typed
  `Record<string, string>`.

### Preserve sensor calibration across re-flashes (EESAVE) + invalidate stale calibration

> Branch `sensor-eeprom-calib-persist` (2026-06-14). A calibrated node was
> reading 0% in a plant pot. Investigation confirmed the measurement direction
> assumption is **correct** (verified against `hardware/sensor/Sensor.sch`: the
> soil cap `C8` shunts the 500 kHz excitation through `R5` into a `D4`/`C7`/`R6`
> envelope detector, so wetter soil → lower raw reading — matching the firmware's
> `min=wet`/`max=dry` sort and `100 - map(...)` inversion). The 0% was stale,
> wrong-scale calibration: commit `21ec50c` changed the raw ADC scale, but the
> `EESAVE` fuse was off so every flash wiped EEPROM to placeholder defaults
> (650/850) that no longer match the new scale. No measurement/calibration
> *logic* was changed.

#### Changed
- **`sensor/platformio.ini`** — `board_fuses.hfuse` `0xDF` → `0xD7` (clears bit 3
  → `EESAVE` programmed) so the pre-flash chip-erase **preserves EEPROM**.
  Calibration now survives same-version re-flashes; the `VERSION`/`SUBVERSION`
  guard in `InitializeEeprom()` (`sensor/src/wpw_EEPROM.cpp`) becomes the sole
  arbiter of when calibration is re-defaulted. Re-apply with
  `pio run -t fuses -e TX`.
- **`sensor/include/wpw_Version.h`** — `SUBVERSION` `0` → `1`. One-time bump that
  forces `InitializeEeprom()` to discard the stale pre-`21ec50c` calibration and
  rewrite valid defaults on the next boot. **A one-time recalibration of each
  node is required after flashing** (air then water).

#### Notes
- Order on hardware: build (`pio run -e TX`) → apply fuses (`pio run -t fuses -e
  TX`) → flash (`pio run -t program -e TX`) → recalibrate. The master
  calibrate-delivery fix (`4d0877f`) must be deployed for the calibrate trigger
  to reach the node.

### Remove the retired 6th sensor channel

> Branch `remove-6th-sensor` (2026-06-14). Removes the leftover references to a
> 6th sensor/channel. The nRF24L01 has 6 pipes but pipe 0 is reserved for the
> writing/ACK address, so the link tops out at **5** sensor channels (also bounded
> by the 5 pump GPIOs the master exposes). The 6th channel never worked — the RX
> firmware opened reading pipe 5 twice instead of a (non-existent) pipe 6.

#### Removed
- **`sensor/include/wpw_Config.h`, `sensor/src/wpw_RXTX.cpp`** — the
  `PIPE_ADDRESS_6` define and its entry in the firmware `pipes[]` table.
- **`core/radio.py`** — the unused 6th entry (`0x5232443236`) from
  `_pipeAddresses`; the reading-pipe loop already only used pipes 1..`CHANNEL_COUNT`.

#### Changed
- **`api/tethys_api/models.py`** — `initializeDatabase` now seeds `CHANNEL_COUNT`
  (= 5) channels instead of a hardcoded 6, via a new module-level `CHANNEL_COUNT`
  constant (mirrors `core.hardware.CHANNEL_COUNT`).
- **`sensor/include/wpw_Config.h`** — `SENSOR_NUMBER` valid range corrected from
  `1-6` to `1-5` (and the value reset from the now-invalid `6` to `1`; it is a
  per-flash node identity — set it to the node being flashed).
- **`README.md`** — `SENSOR_NUMBER` documented as `1–5` (was `1–6`).

#### Fixed
- **6th-sensor reading-pipe bug** — `SetupRadioForRx()` called
  `openReadingPipe(5, pipes[6])` after `openReadingPipe(5, pipes[5])`, opening
  pipe 5 twice and referencing a 7th address that the 6-pipe radio cannot use.
  The duplicate/out-of-range call is removed; the receiver opens reading pipes
  1..5 cleanly.
- **Stray 6th channel in already-initialized databases** — `initializeDatabase`
  now deletes any `Channel` with `number > CHANNEL_COUNT`, so systems seeded
  before this change drop the orphaned channel 6 from the web UI.

### Remote-access hardening (prerequisite for safe VPN access)

> Branch `fix/pump-control-safety-module` (2026-06-13). Hardens the app so it can
> be reached from outside the LAN over an encrypted overlay (Tailscale/WireGuard)
> **without** opening the LAN to the internet. The transport itself is operator
> setup, not code. See `docs/remote-access-hardening.md`.

#### Added
- **`docs/remote-access-hardening.md`** — the env vars, secrets, installer flags,
  the read-now-needs-key behavior, and a Tailscale setup pointer.
- **`globals/secrets.example.py`** — now also documents `API_SECRET_KEY` /
  `WEB_SECRET_KEY` (the Django secret keys, moved out of `settings.py`).
- **`api/tethys_api/tests/test_api_key.py`** — extended for the new posture: reads
  are denied without the key (403) and allowed with it (200); `initializeDatabase`
  is denied on unauthenticated GET (403), method-not-allowed on keyed GET (405),
  denied on keyless POST (403), and allowed on keyed POST.

#### Changed
- **`api/tethys_api/settings.py`, `web/tethys_web/settings.py`** — `DEBUG` now
  reads `TETHYS_DEBUG` (off by default); `SECRET_KEY` reads from the git-ignored
  `globals/secrets.py`; `ALLOWED_HOSTS` appends `TETHYS_ALLOWED_HOSTS`. The web
  settings also exposes `API_AUTH_HEADERS` for its server-side polling.
- **`api/tethys_api/permissions.py`** — `ApiKeyForWrite` → **`ApiKeyRequired`**:
  every request now needs `X-API-Key`, reads included; only `OPTIONS` (CORS
  preflight) is exempt.
- **Read callers now send the key** — the web UI `getCall` (`common.ts`), the core
  daemon (`apiInterface.py`, `radio.py`), and the web backend's server-side polls
  (`jobs.py`, `tools.py`).
- **`api/tethys_api/views.py`** — `initializeDatabase` is now a key-gated `POST`
  (was an open `GET`); `install.sh` calls it via authenticated `POST`.
- **`install/install.sh`, `installServices.sh`** — production-safe `DEBUG` default;
  new `--allowed-hosts` flag; generate `API_SECRET_KEY` / `WEB_SECRET_KEY` (and
  append them to pre-existing `secrets.py` on upgrade); inject `TETHYS_DEBUG` /
  `TETHYS_ALLOWED_HOSTS` into the systemd units.

#### Security
- Sensor data and channel state are no longer readable by anything that merely
  reaches the port; the worst-case (turning on a pump unauthenticated) remains
  closed. Combined with a VPN overlay, this enables remote access with no inbound
  ports and encrypted transport.

### Silent-phase watering gate fix (audit action items #4, #5, #8)

> Branch `fix/pump-control-safety-module` (2026-06-13). Fixes the quiet-hours
> ("silent phase") gate that suppresses **all** watering. Source:
> `docs/audits/2026-06-11 CodeAudit.md` (the silent-phase timezone bug —
> cross-validated ×4 — plus the `loadSilentSchedules` type filter, the fail-open
> `isInSilentPhase()`, and the divergent `TIME_ZONE` config that enabled them).

#### Added
- **`api/tethys_api/silentphase.py`** — `evaluate_silent_phase(schedules, now)`:
  a dependency-free (stdlib only) timezone-aware window evaluator extracted so
  the math that gates all watering is unit-testable without Django. `common.py`
  is now a thin wrapper (ORM query + cached `SILENT_PHASE` state) over it.
- **`api/tethys_api/globals.py`** — `setLastDataUpdate()` / `getLastDataUpdate()`
  helpers so the `LAST_DATA_UPDATE` timestamp is read/written through one
  canonical module global (see the fix below).
- **`api/tethys_api/tests/test_silentphase.py`** — 8 tests: 7 window-math cases
  (inside / before / after a window, the real 22:00→07:00 window, post-midnight
  wraparound, wrong weekday, and that the stored time-of-day is not shifted by
  the placeholder date's historical UTC offset), plus that `loadSilentSchedules`
  returns only enabled schedules of type `silent`.
- **`api/tethys_api/tests/test_last_data_update.py`** — 2 tests pinning the
  `LAST_DATA_UPDATE` wiring (setter mutates the canonical value through an
  alias; a mutating request bumps it).
- **`core/tests/test_action_engine.py`** — 3 tests pinning the fail-closed gate
  (unknown → skip and keep the flag; in-phase → skip; not-silent → evaluate).

#### Changed
- **`globals/config.py`** — single source of truth for the deployment/display
  `TIME_ZONE` (`Europe/Stockholm`), imported by `core/config.py` (the identifier
  the core passes to `silentPhaseStatus`) and the `web` Django settings. The
  **API keeps its Django `TIME_ZONE = 'UTC'`** as its storage zone — schedule
  start times are wall-clock times-of-day, so storing in UTC preserves the
  entered clock-face; the deployment zone is applied at silent-phase evaluation.
- **`api/tethys_api/common.py`** — `refreshSilentPhaseStatus` does all
  comparisons in the caller-supplied timezone (`datetime.now(tz)`), delegating
  the window math to `evaluate_silent_phase`; the cached `SILENT_PHASE`
  timestamps are now timezone-aware.
- **`core/actionEngine.py`** — the silent-phase check is now fail-closed.
- **`api/tethys_api/views.py`** — `setLastDataUpdateNow` / the `lastUpdate`
  endpoint go through the new `globals` helpers instead of a `from import`-aliased
  name (the `lastUpdate` web-polling wire format is unchanged).

#### Fixed
- **[Audit #4] `loadSilentSchedules()` ignored the schedule type** — it returned
  every enabled schedule (`filter(enabled=True)`), so any enabled schedule of any
  type became a quiet-hours window suppressing watering. Now filtered to
  `scheduleType__name="silent"`, matching its docstring.
- **[Audit #4] silent-phase window compared mismatched time bases** — the window
  was rebuilt as a *naive* datetime from a schedule's UTC `.hour/.minute` and
  compared against the server's *naive local* `datetime.now()`, offsetting the
  window by the server's UTC↔local difference (and aware-vs-naive compares could
  `TypeError`). Both sides are now timezone-aware in the configured zone.
- **[Audit #5] divergent `TIME_ZONE`** — `core`/`web` now share one
  deployment-zone definition (`globals/config.py`). The API deliberately keeps a
  `UTC` storage zone (see below); the previous divergence was a bug only because
  the old window math mishandled it.
- **silent-phase window shifted by an hour (icon failed to appear)** — schedule
  start times are wall-clock times-of-day stored on a placeholder date
  (`1900-01-01`). The evaluator localized that value with `astimezone()`, which
  uses the *placeholder date's* historical UTC offset (Stockholm was `+01:00` in
  1900 vs `+02:00` in summer today), shifting a 22:00 window to 23:00 — so at
  22:30 the gate read "not silent" and the UI icon stayed hidden while the
  schedule UI still showed 22:00–07:00. The evaluator now reads the stored UTC
  clock-face as the time-of-day and re-anchors it on today's date in the
  comparison zone (no cross-date `astimezone`).
- **[Audit #8] `isInSilentPhase()` → `None` was treated as "not silent"
  (fail-open)** — when the API is unreachable the engine watered blind. It now
  fails closed: an unknown status skips watering for that pass.
- **`LAST_DATA_UPDATE` never reached `common.py`** — `views.setLastDataUpdateNow`
  rebound a `from import`-aliased copy, so the canonical `globals.LAST_DATA_UPDATE`
  stayed `datetime.min` and the silent-phase "data update" recalc trigger never
  fired (an edited/added/removed schedule was only picked up at the next window
  boundary). Reads/writes now share one value via the `globals` helpers, and the
  recalc comparison localizes the naive timestamp to compare against the
  timezone-aware last-calculation time.

### Communication-protocol hardening

> Branch `fix/pump-control-safety-module` (2026-06-13). Makes the nRF24 link
> between the sensor nodes and the Pi master more robust (owner-reported
> unreliability). Source: `docs/audits/2026-06-13 - ProtocolReview.md` (findings
> P-01..P-07).

#### Added
- **`core/protocol.py`** — dependency-free (stdlib `struct` only) wire-format
  layer: versioned, fixed-size framing with validate-don't-raise parsing
  (`message_type`, `parse_sensor_reading`, `build_config_payload`), channel↔pipe
  mapping, and a `ConfigCache`. `radio.py` is now a thin driver over it, so the
  framing rules are unit-testable without `pyrf24`/`numpy`/GPIO.
- **`core/tests/test_protocol.py`** — 9 tests (battery-alert parsed, malformed
  frames never raise, version drop, config round-trip, pinned wire sizes,
  channel↔pipe mapping, config cache).
- **Versioned wire format** — a leading `ProtocolVersion` byte on both message
  structs, `__attribute__((packed))` + `static_assert` size checks in
  `sensor/include/wpw_RXTX.h`, and `PROTOCOL_VERSION` / `PAYLOAD_SIZE` constants
  in `wpw_Config.h`, mirrored by the Python `struct` formats.

#### Changed
- **`core/radio.py`** — answers `GETCONFIG` from an in-memory `ConfigCache`
  (warmed by `refreshConfigCache`) instead of a blocking HTTP GET inside the
  sensor's listen window; reads a fixed `PAYLOAD_SIZE` (no `getDynamicPayloadSize`
  with dynamic payloads disabled); reserves pipe 0 and maps channels 1:1 onto
  reading pipes 1..N; drains the whole RX FIFO; `setPayloadSize`/`setRetries`;
  per-call HTTP `REQUEST_TIMEOUT`.
- **`core/tethys_core.py`** — warms the config cache at startup and once per core
  loop pass (out of the radio response window).
- **`sensor/src/wpw_RXTX.cpp`** — `setPayloadSize`/`setRetries`, version byte on
  every outbound frame, version check on the received config, config-reply
  timeout 200 ms → 500 ms.
- **`sensor/src/WirelessPlantWatering.cpp`** — boot config handshake is now a
  bounded 5 retries with linear backoff that falls back to the EEPROM-cached
  config (was up to 1000× at 1 s, draining battery).

#### Fixed
- **[P-01]** master silently discarded a sensor's whole reading on a low battery
  (`DATATYPE_SENSORDATA_BATTERYALERT` matched no dispatch branch); both data
  types now save, and the alert is parsed + logged.
- **[P-02]** master read an undefined dynamic payload size (could flush the RX
  FIFO) while dynamic payloads were disabled — now a fixed payload size.
- **[P-03]** racy config handshake + boot retry storm (cache-served reply + a
  500 ms window + bounded backoff with EEPROM fallback).
- **[P-04]** a short/garbage frame raised an unhandled exception in the radio
  loop — parsing now validates length+version and never raises;
  `handlePayload` always resumes listening.
- **[P-05/06/07]** fragile unversioned struct layout, sensor bound to pipe 0, and
  FIFO drain that kept only the last frame.

#### Known limitations / coordinated flash
- **Not backward-compatible:** the version byte + fixed 8-byte payload mean the
  master and every sensor must be flashed together. A node on old firmware uses
  the 32-byte default payload → CRC mismatch → no ACK → it goes dark (clean, not
  corrupting; any stray frame is dropped by the version check). A length-based
  compatibility mode is possible if a phased rollout is ever needed.
- The low-battery **flag is not yet persisted** (`SensorData` has no column); the
  saved voltage carries the signal and the alert is logged. Tracked in `TODO.md`.
- The legacy Arduino `#ifdef RX` firmware receiver has since been **removed**
  (see the entry at the top of this changelog).

### API key for mutating endpoints (audit #3)

> Branch `fix/pump-control-safety-module` (2026-06-13). Implements the audit's
> **action-order item #3 — "lock down the API"** (CRIT-Security).
> Sources: `docs/audits/2026-06-11 CodeAudit.md`,
> `docs/handoffs/2026-06-13 - 01 - API key for mutating endpoints (audit 3).md`.

#### Added
- **`api/tethys_api/permissions.py`** — `ApiKeyForWrite`: a single shared API key
  now gates **all mutating requests** (POST/PUT/PATCH/DELETE) via an `X-API-Key`
  header, compared constant-time, fail-closed. Safe methods (GET/HEAD/OPTIONS)
  stay open, so reads and the CORS preflight are unaffected.
- **`globals/secrets.py`** (git-ignored) as the single key source read by both the
  Django API and the core, with a committed `secrets.example.py` template.
- **Web Settings popup** (`layout.html`) — masked field to store the key locally
  (browser `localStorage`); `common.ts` injects the header into the four mutating
  fetch wrappers; `channel.ts` prompts to set the key on a 403.
- **`install/deploy-static.sh`** — one-command frontend deploy (`tsc` + copy to
  the nginx `staticcollect` dir + permissions).
- **`api/tethys_api/tests/test_api_key.py`** — 7 tests covering the permission.

#### Changed
- **`api/tethys_api/settings.py`** — loads `TETHYS_API_KEY`, sets `REST_FRAMEWORK`
  defaults (permission class; empty auth classes to avoid session/CSRF), and adds
  `x-api-key` to `CORS_ALLOW_HEADERS`.
- **`core/apiInterface.py`, `core/radio.py`** — send the key on their POSTs
  (action log, sensor data).
- **`install/install.sh`** — generates `secrets.py` with a random key on first
  install (idempotent) and prints it.

#### Known limitations
- Traffic is plain HTTP on the LAN, so the key is sniffable (raises the bar, not
  transport security). `initializeDatabase` is a state-changing GET and stays open
  under the method-based scope. `DEBUG=False` and moving the Django `SECRET_KEY`s
  into `secrets.py` remain follow-ups (the secrets-file convention is now in place).

### Pump-control safety module — phase 1

> Branch `fix/pump-control-safety-module`, commit `f992d87` (2026-06-13).
> Implements the audit's **action-order item #2 — [C-02] "no pump max-runtime
> kill-switch"** — for the **automatic / core watering path**, plus the
> 6-vs-5 channel `IndexError`, and adds the project's first test suite.
> Sources: `docs/audits/2026-06-11 CodeAudit.md`,
> `docs/handoffs/2026-06-13 - 00 - Pump-control safety module (phase 1).md`.

#### Added
- **`core/gpioAdapter.py`** — GPIO is now reached through a `GpioAdapter` seam so
  the controller never imports `lgpio` directly. `LgpioAdapter` (lazy `lgpio`
  import; per-operation open → claim → write → close) for production;
  `FakeGpioAdapter` records every write for tests; `GpioError` normalises
  backend errors.
- **`core/pumpController.py`** — single deep pump-control module for the core
  path: `run_pump` / `activate` / `deactivate` / `stop_all` / `is_running`. Hard
  **`MAX_PUMP_SECONDS = 300`** flood clamp, `threading.Timer` auto-off,
  `try`/`finally` best-effort drive-LOW on failure, real success/failure returns,
  valve shared-PUMP-pin ref-counting, channel-bounds validation, and a
  `max_concurrent` guard (default `1`). `make_controller()` wires `lgpio` and
  drives all lines LOW on construction (fail-safe boot).
- **First test suite** — `code/master/core/tests/` (16 tests, runnable without
  `lgpio`), `pytest.ini`, and `install/python-requirements-dev.txt` (pytest only,
  dev-only — production requirements untouched). Addresses the audit's
  "zero tests" finding for this module.
- **Fail-safe shutdown** in `core/tethys_core.py` — `pumpController.shutdown()`
  registered on `SIGTERM` and `atexit`, driving all lines LOW so a crash or
  restart can never leave a pump energised.

#### Changed
- **`core/actionEngine.py`** — the watering path now calls `run_pump`
  **non-blocking**; the DB action-log write moved into the timer's `on_complete`
  callback, so the radio keeps listening while a pump runs. A channel deferred
  because the controller is busy keeps its flag set and retries on the next loop
  pass.
- **`core/tethys_core.py`** — builds the pump controller once and passes it to
  `handleActions`; drives all lines LOW on boot.
- **Behaviour change:** pumping is now timer-driven / non-blocking, and
  `max_concurrent = 1` defers a second simultaneous channel to the next loop pass
  (previously concurrent). Reverting to concurrent is a one-line default.
- **`core/hardware.py` / `core/config.py`** — `CHANNEL_COUNT`
  (`= len(Pins.CHANNELS) = 5`) is now the single source of truth;
  `FlagHandler.channelFlags` length derives from it.

#### Fixed
- **[C-02] (automatic path)** — a pump could turn on and never turn off. Every
  "pump on" is now clamped to `MAX_PUMP_SECONDS` and has a guaranteed off (timer
  + `try`/`finally`), closing the worst verified audit risk for the core path.
- **6-vs-5 channel `IndexError`** — `FlagHandler` previously had 6 hardcoded
  flags while only 5 GPIO channel pins exist; `core/radio.py` now ignores packets
  from pipes beyond `CHANNEL_COUNT` instead of indexing past the list.
- **Lying success returns** — the new controller reports the real result of GPIO
  writes (`False` on failure) instead of the old `channel.setOutputState`
  "return `True` even after a swallowed error" behaviour.

#### Deprecated
- **`core/channel.py`** — kept only for the Django API's manual
  activate/deactivate path, now carrying a deprecation note. Scheduled for removal
  in phase 2 when the API is routed through the controller. Do not add new
  callers.

#### Removed
- Dead `FLAG_HANDLER` singleton from `core/config.py`.

#### Known limitations / still open (by design — deferred)
- **[H-01] two GPIO owners** remains open: the core (`pumpController`) and the API
  (`channel.py`) both still claim GPIO per-operation. The per-operation lifecycle
  is kept deliberately so the new module coexists with the API without
  `GPIO_BUSY`. Closing H-01 is **phase 2** (API → core command queue).
- **[C-02] manual-activate auto-off** is implemented for `pumpController.activate()`
  but **not yet wired to the API's `channel_single_action`** — the API manual
  "activate" still has no server-side auto-off until phase 2.
- **[C-01] core async startup** untouched — assessed as mostly a false alarm (the
  synchronous `while True` does run watering + radio; only `fan.control_fan()` is
  never scheduled). The async fix is deferred and is a co-requisite of phase 2.
- Not in this change: API authentication, `DEBUG = False`, `SECRET_KEY` out of
  git, silent-phase timezone/type-filter fixes, `requests` timeouts, the
  polling-timer leak, and firmware findings.

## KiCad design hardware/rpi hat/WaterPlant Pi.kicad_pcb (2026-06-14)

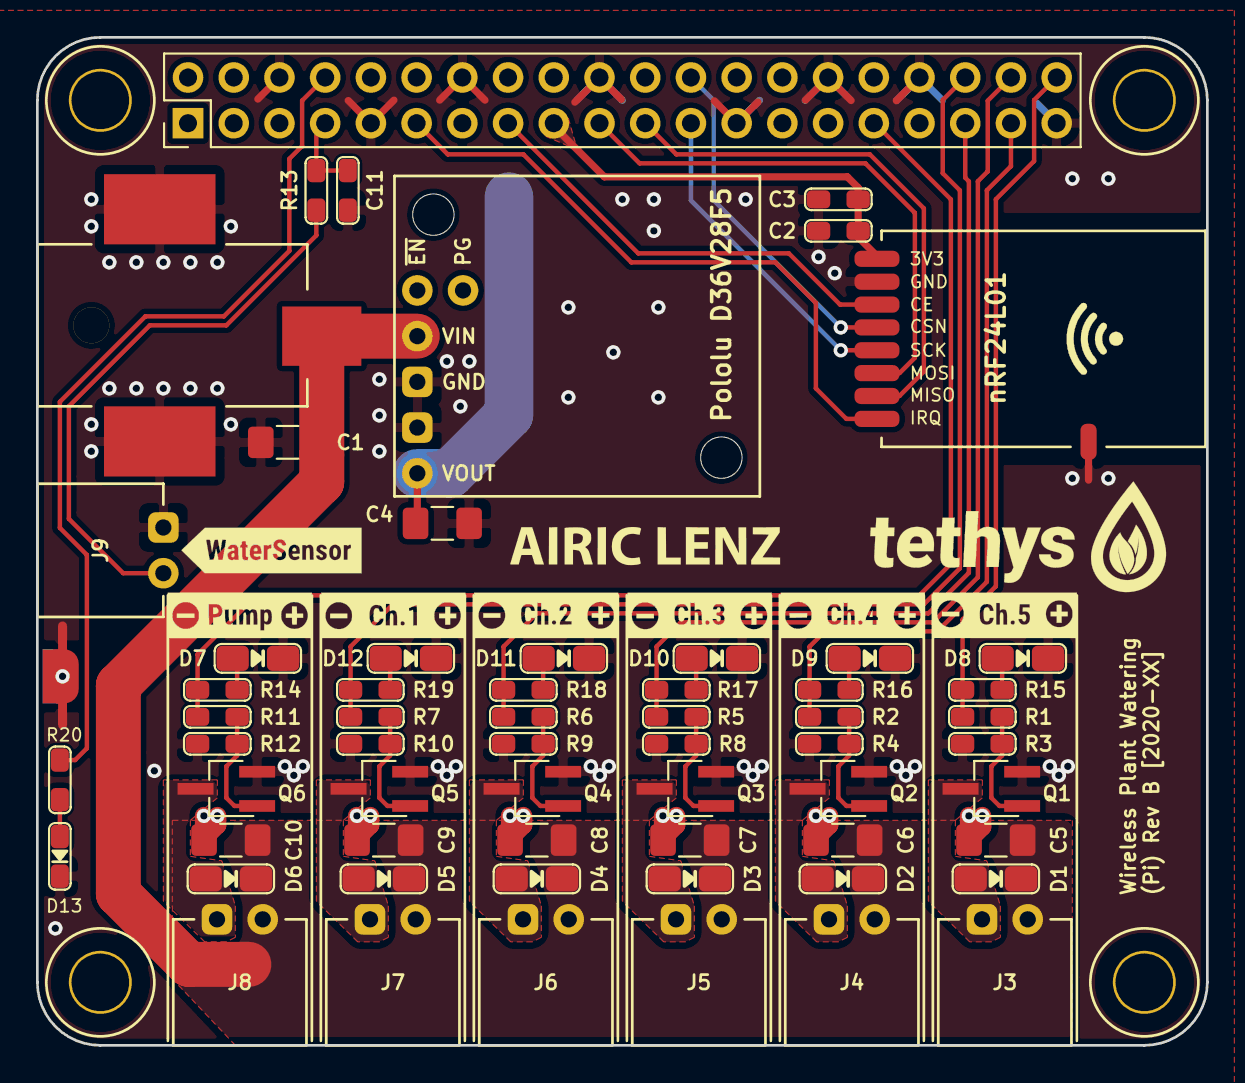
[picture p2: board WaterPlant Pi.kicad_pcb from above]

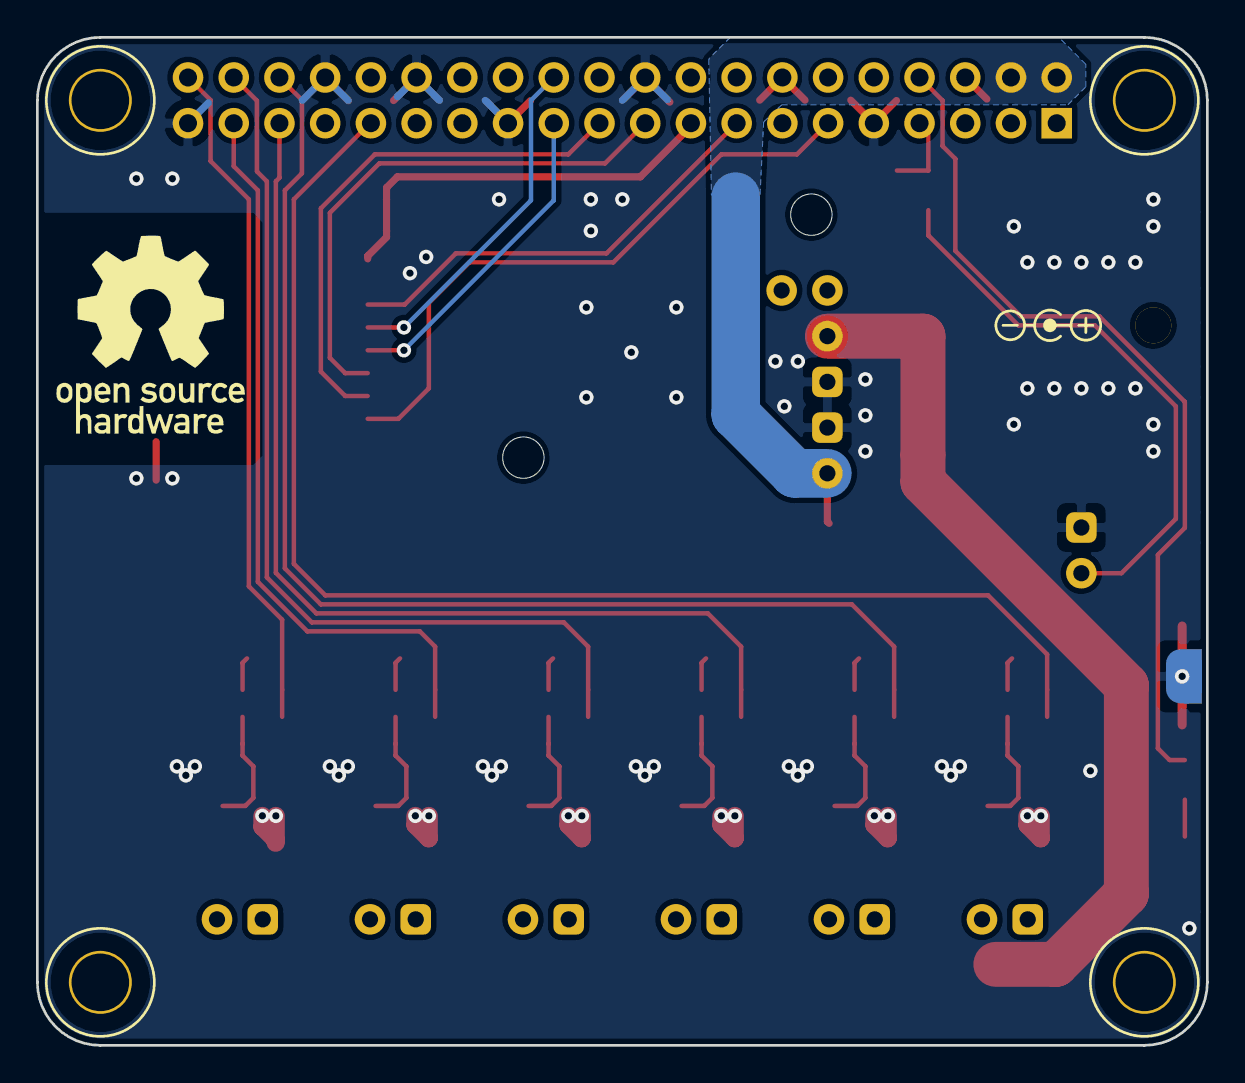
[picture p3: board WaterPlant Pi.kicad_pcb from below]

Board: 2 copper layers, 65.0 x 56.0 mm, 69 parts (2 on the bottom side), 38 nets.

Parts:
BatteryPolaritySign: VAL**; Logo_BatteryPolarity
C1, C4, C5, C6, C7, C8, C9: 10uF 50V; C_1206_3216Metric_Pad1.42x1.75mm_HandSolder
C2: 0.1uF 16V; Device_0603_Handsoldering
C3, C11: 1uF 16V; Device_0603_Handsoldering
C10: 10uF 25V; C_1206_3216Metric_Pad1.42x1.75mm_HandSolder
D1, D2, D3, D4, D5, D6: Schottky 2A; Diode_0805_HandSoldering
D7, D8, D9, D10, D11, D12: LED_Small; Diode_0805_HandSoldering
D13: LED_Small; Diode_0603_Handsoldering
DR1, DR2, DR3, DR4: Drill_Hole; Hole_M3_NPTH_Mounting
J1: Conn_02x20_Odd_Even; PinHeader_2x20_P2.54mm_Vertical
J2: Barrel_Jack; POWER_JACK_2.1_SMD
J3, J4, J5, J6, J7, J8, J9: Conn_01x02_Female; Connector_JST_XH_02x01_angeled
L1: Logo_OSH; Logo_OSHW_Silk_10mm
Logo1: Logo_Airic_Lenz; Logo_AiricLenz_Silk_15mm
MOD1: Module_nRF24L01; Module_nRF24L01_SMD
Q1, Q2, Q3, Q4, Q5, Q6: DMG3418L; TSOT-23_HandSoldering
R1, R2, R5, R6, R7, R11: 470Ω; Device_0603_Handsoldering
R3, R4, R8, R9, R10, R12: 10kΩ; Device_0603_Handsoldering
R13, R14, R15, R16, R17, R18, R19, R20: 1kΩ; Device_0603_Handsoldering
TP1: TESTPOINT; Testpoint_GND
U1: Module_Pololu_D36V28F5; Module_Pololu_5V_D36V28F5

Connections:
+3V3: C2.2, C3.2, J1.1, J1.17, MOD1.1
+5V: C4.1, J1.2, J1.4, U1.1
+12V: C1.1, C5.1, C6.1, C7.1, C8.1, C9.1, C10.1, D1.1, D2.1, D3.1, D4.1, D5.1, D6.1, J2.1, J3.2, J4.2, J5.2, J6.2, J7.2, J8.2, U1.4
GND: C1.2, C2.1, C3.1, C4.2, C5.2, C6.2, C7.2, C8.2, C9.2, C10.2, C11.1, D7.1, D8.1, D9.1, D10.1, D11.1, D12.1, D13.1, J1.6, J1.9, J1.14, J1.20, J1.25, J1.30, J1.34, J1.39, J2.2, J9.1, MOD1.2, Q1.2, Q2.2, Q3.2, Q4.2, Q5.2, Q6.2, R3.2, R4.2, R8.2, R9.2, R10.2, R12.2, TP1.1, U1.2, U1.3
GPIO_4_WATER: C11.2, J1.7, R13.2
GPIO_06_PUMP: J1.31, R11.2, R14.1
GPIO_08_CSN: J1.24, MOD1.4
GPIO_09_MISO: J1.21, MOD1.7
GPIO_10_MOSI: J1.19, MOD1.6
GPIO_11_SCK: J1.23, MOD1.5
GPIO_14_LED: J1.8, R20.2
GPIO_16_CH1: J1.36, R7.2, R19.1
GPIO_17_IRQ: J1.11, MOD1.8
GPIO_19_CH2: J1.35, R6.2, R18.1
GPIO_20_CH3: J1.38, R5.2, R17.1
GPIO_21_CH5: J1.40, R1.2, R15.1
GPIO_22_CE: J1.15, MOD1.3
GPIO_26_CH4: J1.37, R2.2, R16.1
unnamed: D1.2, J3.1, Q1.3
unnamed: D2.2, J4.1, Q2.3
unnamed: D3.2, J5.1, Q3.3
unnamed: D4.2, J6.1, Q4.3
unnamed: D5.2, J7.1, Q5.3
unnamed: D6.2, J8.1, Q6.3
unnamed: D7.2, R14.2
unnamed: D8.2, R15.2
unnamed: D9.2, R16.2
unnamed: D10.2, R17.2
unnamed: D11.2, R18.2
unnamed: D12.2, R19.2
unnamed: D13.2, R20.1
unnamed: J9.2, R13.1
unnamed: Q1.1, R1.1, R3.1
unnamed: Q2.1, R2.1, R4.1
unnamed: Q3.1, R5.1, R8.1
unnamed: Q4.1, R6.1, R9.1
unnamed: Q5.1, R7.1, R10.1
unnamed: Q6.1, R11.1, R12.1

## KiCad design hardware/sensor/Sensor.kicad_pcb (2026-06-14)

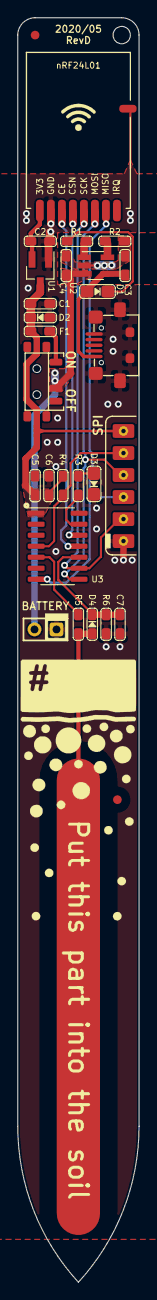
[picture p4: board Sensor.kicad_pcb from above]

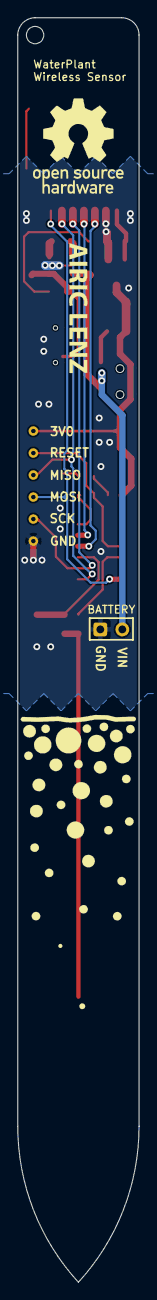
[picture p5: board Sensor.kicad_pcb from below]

Board: 2 copper layers, 14.0 x 145.9 mm, 32 parts (2 on the bottom side), 20 nets.

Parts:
C1, C2, C6, C7: 1u; Device_0603_Handsoldering
C3, C4: 4.7uF; Device_0603_Handsoldering
C5: 0.1u; Device_0603_Handsoldering
C8: C_Soil; WaterPlant_C_Soil
D1: LED_BLUE; LED_0805_Handsoldering
D2, D4: D_Small; Diode_0603_Handsoldering
D3: LED_RED; LED_0805_Handsoldering
DR1: Drill_Hole; Hole_M2_NPTH
F1: JK-SMD0603-005; Device_0603_Handsoldering
FID1, FID2: Fiducial
J1: BatteryConnector; Connector_PinHeader_02x1
J2: PowerSwitch; Switch_SMD_K3-1296S-E2
J3: USB_B_Micro; Connector_USB_Micro_B_C77238
J4: Conn_01x06_Female; Connector_FlatHeader-06x1_SPI
L1: Logo_OSH; Logo_OSHW_Silk_10mm
Logo1: Logo_Airic_Lenz; Logo_AiricLenz_Silk_15mm
MOD1: nRF24L01; Module_nRF24L01_SMD
R1, R2, R3: 2k; Device_0603_Handsoldering
R4, R5: 10k; Device_0603_Handsoldering
R6: 510k; Device_0603_Handsoldering
U1: MCP1700-3002E_SOT23; SOT-23_Handsoldering
U2: MCP73831-2-OT; SOT-23-5_HandSoldering
U3: ATtiny84-20SSU; SOIC-14_3.9x8.7mm_P1.27mm

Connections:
+3V0: C2.2, MOD1.1, U1.2
+5V: C3.1, D1.2, J3.1, U2.4
D2_CLKOUT: R5.1, U3.5
D4_A6_MOSI_SDA: J4.3, MOD1.7, U3.7
D5_A5_MISO: J4.4, MOD1.6, U3.8
D6_A4_SCK_SCL: J4.2, MOD1.5, U3.9
D7_A3_CAPACITANCE: C7.1, D4.1, R6.2, U3.10
D8_A2: MOD1.3, U3.11
D9_A1: MOD1.4, U3.12
GND: C1.2, C2.1, C3.2, C4.2, C5.2, C6.2, C7.2, D2.2, D3.1, J1.1, J3.5, J3.6, J4.1, MOD1.2, R2.1, R6.1, U1.1, U2.2, U3.14
unnamed: C8.1, D4.2, R5.2
unnamed: D1.1, R1.2
unnamed: D3.2, R3.1
unnamed: F1.2, J2.3
unnamed: R1.1, U2.1
unnamed: R2.2, U2.5
unnamed: R3.2, U3.13
RESET: J4.5, R4.2, U3.4
VBAT: C4.1, J1.2, J2.2, U2.3
VCC: C1.1, C5.1, C6.1, D2.1, F1.1, J4.6, R4.1, U1.3, U3.1

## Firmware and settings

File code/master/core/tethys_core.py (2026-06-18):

from __future__ import print_function

import sys
import os
import atexit
import signal
import threading
import time

from hardware import Pins
from radio import Radio
from pumpController import make_controller


root_path = os.path.abspath(os.path.join(os.path.dirname(__file__), '../'))
if root_path not in sys.path:
    sys.path.append(root_path)

import core.actionEngine as actionEngine
import core.manualCommands as manualCommands
import core.fanController as fan



# :::::::::::::::::::::::::::::::::::::::::::::::::::::::::::::::::::::::::::::
# :::::::::::::::::::::::::::::::::::::::::::::::::::::::::::::::::::::::::::::
# :::::::::::::::::::::::::::::::::::::::::::::::::::::::::::::::::::::::::::::

# This Service handels the interface to the nRF24L01+ module.
# It initializes an interrupt driven listening function that reacts to
# messages from the moisture sensors to the radio module of this master unit.

# :::::::::::::::::::::::::::::::::::::::::::::::::::::::::::::::::::::::::::::
# :::::::::::::::::::::::::::::::::::::::::::::::::::::::::::::::::::::::::::::
# :::::::::::::::::::::::::::::::::::::::::::::::::::::::::::::::::::::::::::::


radioWrapper = Radio()
radioWrapper.initializeRadio()

# Warm the config cache before we start serving GETCONFIG requests, so the very
# first sensor handshake after boot is answered from memory rather than a
# blocking HTTP GET inside the sensor's short listen window.
radioWrapper.refreshConfigCache()

# Single owner of the watering GPIO. Built once; drives all lines LOW on
# construction (fail-safe boot) and again on shutdown so a crash/restart can
# never leave a pump energised.
pumpController = make_controller()

def _shutdownPumps(*_args):
    pumpController.shutdown()

atexit.register(_shutdownPumps)
signal.signal(signal.SIGTERM, lambda *_: (_shutdownPumps(), sys.exit(0)))

print("Tethys Core started...")

# =============================================================================
def handleCoreActivities():

    while True:
        # Keep config replies cache-served and out of the radio response
        # window. Runs between listen windows, so its HTTP calls never delay a
        # sensor's handshake.
        radioWrapper.refreshConfigCache()
        radioWrapper.handleRadioEvents(timeOutInSec = 30)
        actionEngine.handleActions(pumpController)


# Manual taps drain on this cadence, on their own thread, independent of the 30s
# radio-listen window above -- so the web "Test Channel" toggle acts within ~1s
# instead of waiting for the current window to end.
MANUAL_DRAIN_INTERVAL_SEC = 1


# =============================================================================
def _drainManualCommands():
    while True:
        try:
            # Run any manual "Test Channel" taps from the web UI through the same
            # single pump controller as automatic watering, so the one-channel
            # power limit is enforced across both paths. The controller's lock
            # serialises this thread against actionEngine on the main thread.
            manualCommands.drain(pumpController)
        except Exception as e:
            # A transient error (e.g. an API blip) must not kill the thread and
            # silently end manual control -- log it and keep polling.
            print(f"manual-drain loop error: {e}")
        time.sleep(MANUAL_DRAIN_INTERVAL_SEC)


# =============================================================================
def main():

    # The core is synchronous at heart (blocking lgpio/radio busy-waits), so each
    # concurrent activity runs on its own daemon thread rather than an asyncio
    # task. (The previous asyncio.create_task(handleCoreActivities()) blocked
    # forever evaluating the sync while-loop, so the fan task was never even
    # created.) Daemon threads exit with the process; the SIGTERM/atexit hook
    # above still drives the pumps LOW on shutdown.
    threading.Thread(target=_drainManualCommands, daemon=True).start()
    threading.Thread(target=fan.control_fan, daemon=True).start()

    # Radio listening + automatic watering run on the main thread.
    handleCoreActivities()


# :::::::::::::::::::::::::::::::::::::::::::::::::::::::::::::::::::::::::::::
if __name__ == "__main__":

    main()

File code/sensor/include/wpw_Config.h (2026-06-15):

#ifndef wpw_Config

    #define wpw_Config

	#include <Arduino.h>
    #include <RF24.h>
	#include <wpw_Version.h>



    // ================================================ //
    // C H A N G E   T H E S E   A C C O R D I N G L Y  //
    // ================================================ //
                                                        //
    #define SENSOR_NUMBER       5 // 1-5    			//
                                                        //
	//#define DEBUG				 						//
                                                        //
    // Change the first 4 bytes to be identical for		//
	// giving a certain namespace			            //
	// The last byte needs to be unique for each pipe.	//
    #define PIPE_ADDRESS_0      0x5232443230  			//
    #define PIPE_ADDRESS_1      0x5232443231  			//
    #define PIPE_ADDRESS_2      0x5232443232  			//
    #define PIPE_ADDRESS_3      0x5232443233  			//
    #define PIPE_ADDRESS_4      0x5232443234  			//
    #define PIPE_ADDRESS_5      0x5232443235  			//
                                                        //
    // ================================================ //


	#define		LOOPS_PER_MINUTE		6.667		// 9 sec per loop

	// Settle time (in seconds) after boot/calibration before the FIRST measurement
	// is taken and transmitted. The node sleeps through this window one ~9 s
	// watchdog loop at a time (it does NOT block), so it costs almost no power and
	// the effective resolution is ~9 s. Gives the probe time to reach its final
	// monitoring position before the first reported reading.
	#define		STARTUP_SETTLE_SECONDS	60


	// How often (in seconds) the node re-pulls its configuration from the master
	// while running. The pull rides an existing measurement wake (the radio is
	// already powered up), so it adds no extra radio power-up -- only a short
	// settings-only request on the first measurement at/after this interval has
	// elapsed since the last pull. The master answers from its config cache, so
	// the listen window is usually a few ms. Set to 0 to disable periodic pulls
	// entirely (maximum battery saving); the one-time boot-time fetch still
	// happens. NOTE: periodic pulls deliver measure-frequency / TX-power only --
	// calibration stays a boot-only, user-supervised operation.
	#define		PULL_CONFIG_CYCLE_SECONDS	3600	// 1 hour; 0 = disabled


	// ------------------------------------------------
	// Wire protocol (MUST stay in sync with code/master/core/protocol.py)

	// Bump whenever the on-air struct layout changes. A frame whose first byte
	// does not match is dropped instead of mis-parsed.
	#define		PROTOCOL_VERSION		1

	// Fixed on-air payload size in bytes. Both ends call setPayloadSize() with
	// this value; shorter frames are zero-padded by the radio. Must be >= the
	// largest message.
	#define		PAYLOAD_SIZE			8




    // ------------------------------------------------
    // Pin definitions

	#include "wpw_Sleep.h"

	#define     PIN_CE              8
	#define     PIN_CSN             9
	#define     PIN_LED             10
	#define     PIN_BATTERY         A7

	// Port descriptions here as these
	// are used to set port bits:
	#define     PIN_SENSOR_CLOCK    PB2
	#define     PIN_SENSOR_READ     PA3

#endif

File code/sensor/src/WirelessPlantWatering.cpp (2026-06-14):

#include <Arduino.h>

#include "wpw_Config.h"

#include "wpw_Battery.h"
#include "wpw_Blinker.h"
#include "wpw_EEPROM.h"
#include "wpw_RXTX.h"
#include "wpw_Sensor.h"
#include "wpw_WirelessPlantWatering.h"





// ------------------------------------------------
// WATCHDOG / SLEEP

// one loop ~ 9 sec --> 15min = 104.4 loops

uint16_t	_watchdog_loops				= 60 * LOOPS_PER_MINUTE; // 60min / 1h

// Start the down-counter at the settle window so the first measurement is
// deferred ~STARTUP_SETTLE_SECONDS after boot (the node sleeps through it via
// the normal loop/Sleep cycle; each loop is ~9 s, so the value rounds down to a
// whole loop count). After the first capture the counter is reloaded with the
// configured measure interval, so this only affects the first reading.
uint16_t    _watchdog_loop_counter		= STARTUP_SETTLE_SECONDS * LOOPS_PER_MINUTE / 60;


#if PULL_CONFIG_CYCLE_SECONDS > 0

	// Watchdog loops between periodic config pulls, derived from the configured
	// cycle (same seconds->loops idiom as _watchdog_loop_counter above).
	const uint16_t	_config_pull_loops			= PULL_CONFIG_CYCLE_SECONDS * LOOPS_PER_MINUTE / 60;

	// Loops elapsed since the last config pull. The boot-time fetch in setup()
	// counts as the most recent pull, so we start the clock at zero.
	uint16_t		_config_pull_elapsed_loops	= 0;

#endif



// ============================================================================
uint16_t * GetWatchdogLoopPointer()
{
	return &_watchdog_loops;
}






// ============================================================================
// ============================================================================
// ============================================================================
void setup()
{

	#ifdef DEBUG
		Serial.begin(57600);
	#endif

	pinMode(PIN_LED, OUTPUT);

	randomSeed(analogRead(0));

	InitializeRadio();



	delay(750);

	randomSeed(analogRead(0));

	// Do some intial blinks (blink the ID),
	// to show that the device is powered
	for (uint8_t i=0; i<SENSOR_NUMBER; i++)
	{
		DoSimpleBlink(150, 300);
	}
	delay(750);

	SetupRadioForTx();
	InitializeSensor();
	InitializeSleep();
	InitializeEeprom();
	InitializeBattery();

	delay(750);

	// Ask the master for fresh config, but don't camp here draining the
	// battery if it never answers (it may be busy, or this is a first-ever
	// boot with no master in range). A handful of bounded retries with
	// linear backoff, then fall back to the settings already loaded from
	// EEPROM and start measuring. The master answers from its config cache,
	// so a reachable master replies on the first attempt.
	const uint8_t	MAX_CONFIG_RETRIES = 5;
	bool			success            = false;

	for (uint8_t attempt = 0; !success && attempt < MAX_CONFIG_RETRIES; attempt++)
	{
		success = RequestConfiguration();

		if (!success)
		{
			// linear backoff between attempts: 1s, 2s, 3s, ...
			delay((uint32_t)(attempt + 1) * 1000);
		}
	}

	if (success || IsSettingsFlagDirty())
	{
		SaveSettingsToEeprom();
	}

	delay(100);

}



// ============================================================================
// ============================================================================
// ============================================================================
void loop()
{

	while(true)
	{

		if (_watchdog_loop_counter == 0)
		{
			ReadBattery();
			ReadSensor();
			RadioPowerUp();
			HandleTransmitter();

			#if PULL_CONFIG_CYCLE_SECONDS > 0

				// Ride this measurement's radio-on window for a periodic config
				// pull -- no extra power-up. Only when the measurement actually
				// reached the master (a failed link would just fail the pull too).
				if (GetTxStatus() != TX_FAILURE)
				{
					// Pull on the first measurement at/after the cycle has
					// elapsed. Comparing the *remaining* loops (rather than
					// accumulating past the threshold) keeps the counter < the
					// threshold, so the uint16_t sum can never overflow.
					if (_config_pull_loops - _config_pull_elapsed_loops <= _watchdog_loops)
					{
						// Settings-only, silent pull; persist silently if changed.
						if (RequestConfiguration(true))
						{
							SaveSettingsToEeprom(false);
						}

						_config_pull_elapsed_loops = 0;
					}
					else
					{
						_config_pull_elapsed_loops += _watchdog_loops;
					}
				}

			#endif

			RadioPowerDown();


			if (GetTxStatus() == TX_FAILURE)
			{
				// loop for about 15min, then try again...
				_watchdog_loop_counter = 100; // random(5) + 1;

				// Four short flashes: extends the radio-status family
				// (1 = config ok, 2 = no reply, 3 = bad frame, 4 = send failed).
				DoSimpleBlink(15, 150);
				DoSimpleBlink(15, 150);
				DoSimpleBlink(15, 150);
				DoSimpleBlink(15, 0);
			}
			else
			{
				_watchdog_loop_counter = _watchdog_loops;
			}

		}

		DoSimpleBlink(5, 0);

		Sleep();

		_watchdog_loop_counter--;

	}



}

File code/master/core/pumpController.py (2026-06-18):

# =============================================================================
# Pump controller — the single deep module that drives watering hardware safely.
#
# Replaces the old core/channel.setOutputState path. Every "pump on" is clamped to
# a hard maximum, always has a guaranteed "off" (via a timer plus try/finally), and
# reports real success/failure instead of always returning True. Hardware is reached
# only through a GpioAdapter so the module is unit-testable without lgpio / a Pi.
#
# Scope note: this module is the single owner of the watering GPIO. Automatic
# watering and the web UI's manual taps both go through it -- the latter via the
# ManualCommand queue the core drains (see manualCommands.py), not a separate GPIO
# path -- so the max_concurrent guard keeps at most one channel energised across
# every path. The adapter keeps a per-operation claim/write/release lifecycle so it
# coexists with the fan controller's own chip handle without GPIO_BUSY conflicts.
# =============================================================================

import logging
import threading
from datetime import datetime, timezone

from gpioAdapter import GpioError

# Hard ceiling on how long any pump/valve may stay energised, regardless of the
# (unbounded) pumpDurationSeconds coming from the database. This is the flood
# guard.
MAX_PUMP_SECONDS = 300


class PumpError(Exception):
    '''Raised when a pump could not be started (e.g. the ON write failed).'''
    pass


# =============================================================================
class RunHandle:
    '''Returned by run_pump/activate. Wraps the auto-off timer so callers (and
    tests) can cancel it or wait for it to fire.'''

    def __init__(self, channel, timer):
        self.channel = channel
        self._timer = timer

    def cancel(self):
        self._timer.cancel()

    def wait(self, timeout=None):
        # threading.Timer is a Thread; FakeTimer in tests provides join() too.
        join = getattr(self._timer, "join", None)
        if join is not None:
            join(timeout)


# =============================================================================
class PumpController:

    def __init__(
        self,
        gpio,
        pins,
        channel_count=None,
        max_seconds=MAX_PUMP_SECONDS,
        max_concurrent=1,
        timer_factory=threading.Timer,
        # Timezone-aware UTC so the logged start/end are absolute instants. A
        # naive local clock used to be stored mislabeled as UTC by the API,
        # which made every action span the local UTC offset (e.g. +2h) instead
        # of the real pump duration.
        clock=lambda: datetime.now(timezone.utc),
        logger=None,
    ):
        self._gpio = gpio
        self._pins = pins
        self._channel_count = channel_count if channel_count is not None else len(pins.CHANNELS)
        self._max_seconds = max_seconds
        self._max_concurrent = max_concurrent
        self._timer_factory = timer_factory
        self._clock = clock
        self._log = logger or logging.getLogger("tethys.pump")

        self._lock = threading.RLock()
        self._timers = {}           # channel -> active auto-off timer
        self._active_valves = set() # valve channels currently energising the shared PUMP pin

    # -- public ---------------------------------------------------------------

    def run_pump(self, channel, seconds, channel_type, on_complete=None):
        '''Energise `channel` and guarantee it is switched off after the clamped
        duration. Non-blocking: returns a RunHandle immediately, or None if the
        controller is already at max_concurrent active pumps (the caller should
        leave its flag set and retry on the next loop pass).

        Raises ValueError for an out-of-range channel and PumpError if the ON
        write fails.'''
        self._validate(channel)
        seconds = self._clamp(seconds)

        with self._lock:
            # Busy guard: another channel is already pumping and we are at the
            # concurrency limit. Re-running the *same* channel is allowed (it
            # supersedes the in-flight run) and does not count against the limit.
            if channel not in self._timers and len(self._timers) >= self._max_concurrent:
                self._log.info(
                    "channel %s pump deferred: %s pump(s) already active",
                    channel, len(self._timers),
                )
                return None

            self._cancel_timer_locked(channel)

            start = self._clock()
            try:
                self._turn_on(channel, channel_type)
            except GpioError as e:
                # Never report success after a failed write. Best-effort off, then raise.
                self._safe_off(channel, channel_type)
                raise PumpError(f"failed to start pump on channel {channel}: {e}") from e

            timer = self._timer_factory(
                seconds, self._auto_off, args=(channel, channel_type, start, on_complete),
            )
            timer.daemon = True
            self._timers[channel] = timer
            timer.start()
            self._log.info("channel %s pumping for %ss (%s)", channel, seconds, channel_type)
            return RunHandle(channel, timer)

    def activate(self, channel, channel_type):
        '''Manual ON with a mandatory safety ceiling (auto-off after
        max_seconds), so a manual activate can never run forever.'''
        return self.run_pump(channel, self._max_seconds, channel_type)

    def deactivate(self, channel, channel_type):
        '''Explicit OFF. Cancels any pending auto-off timer and drives the line
        LOW. Returns the real result of the write (False on failure) — it never
        lies about success.'''
        self._validate(channel)
        with self._lock:
            self._cancel_timer_locked(channel)
            try:
                self._turn_off(channel, channel_type)
                return True
            except GpioError as e:
                self._log.error("channel %s deactivate failed: %s", channel, e)
                return False

    def is_running(self, channel):
        with self._lock:
            return channel in self._timers

    def stop_all(self):
        '''Cancel every timer and drive all channel pins and the PUMP pin LOW.
        Used for the fail-safe boot and the shutdown hook.'''
        with self._lock:
            for timer in list(self._timers.values()):
                timer.cancel()
            self._timers.clear()
            self._active_valves.clear()
            pins = list(self._pins.CHANNELS) + [self._pins.PUMP]
            try:
                self._gpio.write_pins(pins, 0)
            except GpioError as e:
                self._log.error("stop_all failed to drive pins LOW: %s", e)
                return False
            return True

    # shutdown is an alias used by the SIGTERM/atexit hook in tethys_core.
    shutdown = stop_all
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

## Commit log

2026-06-15 Add sensor firmware-version reporting with dashboard up-to-date indicator
    Sensors report their firmware version (VERSION.SUBVERSION.BUILDNUMBER from
    wpw_Version.h) on boot via a dedicated 5-byte config-request frame. The master
    parses it (protocol.parse_firmware_version), persists the latest value per
    channel after answering the boot-time GETCONFIG, and dedups so a reboot loop
    doesn't re-PUT the same value.
    The API stores it on Channel.sensorFirmwareVersion and, alongside it, exposes
    the latest version read live from the firmware source (tethys_api.firmware) plus
    a comparison status (up_to_date / outdated / ahead / unknown). The channel page
    shows the reported version with a colored hint --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
    [firmware.py, models.py, protocol.py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]
2026-06-15 Add OpenAPI docs via drf-spectacular
    Wire up drf-spectacular to expose an auto-generated OpenAPI schema plus
    Swagger UI and ReDoc for the master API:
    - /api/schema/ - OpenAPI 3 schema
    - /api/docs/ - Swagger UI
    - /api/redoc/ - ReDoc
    The doc endpoints are served with AllowAny so the schema and the UIs that
    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
2026-06-15 Update About popup text and fix repo clone URL
    Replace Lorem ipsum in the web UI About popup with a real project
    description, version, and license, and drop the dead core-temperature
    placeholder (the live value already shows in the footer).
    Fix the git clone URL in README.md and install/readme.md to the
    canonical https://github.com/airiclenz/tethys (the old tethys-v2 name
    only worked via GitHub's redirect).
2026-06-15 Fix non-functional 'add new channel' button and auto-open new channel (#2)
    The add-channel button silently did nothing. addNewChannel() POSTed a body
    with 'triggerLevel: 50', but the Channel model/serializer field is the
    required 'actionTriggerPercent', so the API returned 400 and the handler
    bailed on !response.ok.
    Fixing that exposed a second bug: on success the code did
    parseInt(responseBody), but the POST returns the full channel JSON, not a
    bare number, so selectedChannelNumber became NaN and wedged the settings
    panel toggle. Drop the body read and track the new channel number instead.
    Also auto-open the new channel's settings panel: record the created number
    and, once the summary ref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
2026-06-15 Add moisture and battery-voltage trend charts to Sensor Readings
    The Sensor Readings page now shows two time-series line charts (moisture %
    and battery voltage over time) side by side above the readings table, drawn
    from the data the page already loads.
    - charts.ts (tethys.charts): renders both charts for the selected channel,
    updates in place on channel change / delete, clears when empty. Moisture
    y-axis fixed 0-100%; voltage y-axis auto with a dashed 3.5 V reference line;
    x-axis labels auto-thinned; y-axis ticks show units (% / V).
    - Vendor Chart.js v4.4.6 (UMD) locally so the dashboard works offline.
    - installServices.sh and deploy-static.sh now publish the vendor/ folder.
2026-06-16 Add Playwright UI regression test for sparse-channel settings crash
    Automates the manual check for the channel-settings bug: a headless-Chromium
    test (pytest + Playwright against a Django live server) loads the channels
    page, injects non-contiguous channels 1/2/5 through the page's own render
    path, clicks channel 5, and asserts the settings panel opens with the right
    title and that no uncaught JS error fired. Verified it fails on the original
    channels[number-1] indexing and passes on the fix.
    conftest.py compiles static/ts to static/js first (the JS is no longer
    committed), so tests run against current TypeScript. A test-only settings
    module serves /static/ straight from the source tree; no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
2026-06-16 Add auth-failure banner on page load
    Every API request needs an X-API-Key; a missing or wrong key gets a 403,
    so without the key the dashboard silently failed to load any data. On page
    load afterPageLoad() now probes the cheapest endpoint (GET /api/version/):
    a 403 shows a dismissible warning banner under the header linking to
    Settings, and saving a correct key re-probes and clears it.
    Also corrects the README setup paragraph: the key gates every request
    (reads included), it does not leave read-only views open.
    Adds Playwright regression tests covering banner-on-403 and hidden-on-200.
2026-06-16 Even out measurements/actions table column widths; align headers with rows
    - Measurements: four data columns at col-25 + col-2 delete column (header + rows).
    - Actions: five data columns at col-20 + col-2 delete column (header + rows).
    - Add a hidden 42px spacer in each header's delete cell to match the row button width.
    - Add a .col-1 flex-basis helper.
2026-06-16 Make daphne restart fast: daemon poll thread + capped stop timeout
    The WebSocket poll thread (RepeatTimer in jobs.py) was non-daemon and never cancelled, so on SIGTERM CPython blocked joining it until systemd's 90s stop timeout SIGKILLed daphne, stalling every deploy. Mark it daemon so the interpreter abandons it at shutdown (the interrupted poll is an idempotent GET), and fix the stale 'global thread' declaration so the module-level repeater is actually tracked.
    Backstop: cap daphne.service TimeoutStopSec at 5s so a future shutdown hang can't cost 90s again (a healthy graceful stop measures ~0.6s; SIGKILL is safe here since state lives in the DB/Redis/core and browsers reconnect).
2026-06-16 Add responsive/mobile web UI layer
    Introduce a desktop-first responsive layer on top of the fixed desktop
    design, so the dashboard is usable on phones and narrow windows.
    - responsive.css: new stylesheet, loaded LAST so its @media overrides win.
    Breakpoints: side gutters <=1400px, hamburger nav <=860px, and at <=700px
    tables collapse to labeled cards, settings forms stack to one column,
    charts stack, the footer wraps, and modals go near-full-width.
    - layout.html: add charset + viewport meta, link responsive.css, and wrap the
    nav links in a toggleable dropdown driven by an accessible hamburger button.
    - common.ts: add toggleNav() to open/close the hamburger dropdown.
    - templatter row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
2026-06-17 Keep table headers aligned with rows when the frame narrows
    Table cells are flex items whose .col-* classes set only flex-basis,
    leaving the default min-width:auto. That floors each cell at its own
    content width, so the wider header labels stopped shrinking while the
    shorter-content body columns kept going, drifting out of alignment in
    the fluid range above the 700px cards breakpoint.
    Add min-width:0 to the data columns (.col-2 delete column excluded so
    its 42px button is never clipped) so header and body shrink to the same
    flex-basis share and stay aligned. Same pattern main.css already uses on
    the field rows.
2026-06-17 Keep site header above sensor-reading charts when scrolling
    The sticky #site-header had no z-index, so it and the position:relative
    chart wrappers were both z-index:auto and painted in DOM order — the
    later charts won and covered the header on scroll (visible in phone mode
    where charts stack full-width under the bar). Give the header z-index:60:
    above content, below modal overlays (.overlay = 100).
2026-06-17 Fix mangled site footer in phone mode
    Stack each footer readout label over its value (Pi-Core: / 42.8°C) at all
    widths by composing the strings with a <br>, in common.ts and the layout.html
    placeholders.
    On phone (<=700px) rebuild the footer as a clean flex line: hide the tagline and
    the layout-only spacer columns, let the two readouts size to content and sit
    left with a gap, push the OSH logo to the right edge with margin-left:auto, and
    re-centre the wrapped line vertically with align-content/align-items.
    Also note in README that static/js is generated from static/ts and must not be
    hand-edited.
2026-06-17 Group moisture/battery card values to the right in phone mode
    In folded (<=700px) card mode each table cell is a flex line with
    justify-content:space-between and a ::before label. Single-value cells
    read label-left/value-right, but the Moisture cell renders several nodes
    (icon + percent + comparator) and the low-battery cell renders voltage +
    a warning icon, so space-between spread each node across the card.
    Change the label ::before margin-right from a fixed 0.75rem to auto.
    Auto margins steal main-axis free space before space-between distributes
    any, so the label pins left and the value nodes pack together on the
    right. Single-value cells and the desktop table are unchanged.
2026-06-17 Fix phone-width horizontal scroll from off-screen tooltip and bare chart canvas
    The empty strip on the right edge at phone width (and its horizontal
    scrollbar) came from the shared header, not the modal pop-ups (those are
    position:fixed and add no scroll width):
    - The silent-phase tooltip (.tooltiptext) is position:absolute, width:270px,
    anchored near the top-right of the header. With no offset it grew rightward,
    off-screen, so even while visibility:hidden it laid out and extended the
    document's scrollable width on every page. Anchor it to its right edge so it
    grows left into the viewport, and clamp with max-width: calc(100vw - 7rem)
    (reserving the header controls between the anch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
2026-06-17 Wire "Order 66" menu to a key-gated graceful Pi reboot
    The Order 66 popup linked to a non-existent /shutdown route (404). It now triggers POST /api/reboot/ — a key-gated, POST-only endpoint that runs a graceful `systemctl reboot`, deferred via a detached shell so the 202 flushes before services tear down. Absolute binary paths are used because the service PATH is pinned to the venv bin. The popup OK button calls tethys.requestReboot() (reusing the postCall helper and auth banner); the dead index-shutdown.html template is removed.
    [urls.py, views.py]
2026-06-17 Fix watchdog nightly maintenance silently failing on restricted PATH
    restartServices() ran systemctl/journalctl as bare commands via
    os.system(), but the systemd unit pins PATH to the venv bin
    (Environment=PATH=.../env_tethys/bin), so /bin/sh could not resolve
    either binary (sh: 1: systemctl: not found). The return code was
    ignored and the success print()s ran unconditionally, so the 01:00
    job failed every night while logging success — services were never
    actually restarted and journals never vacuumed.
    Use absolute paths (/usr/bin/systemctl, /usr/bin/journalctl), matching
    the /api/reboot/ endpoint, and check each return code so a future
    failure logs FAILED instead of a false success. No u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
2026-06-17 Fix intermittent nginx 502 / lost /channels redirect from IPv6 localhost upstreams
    proxy_pass targeted the name 'localhost', which resolves to both 127.0.0.1 and ::1, while gunicorn (web :8000, api :5001) and daphne (:8001) bind IPv4 only. nginx round-robined onto [::1], got connect() failed (111: Connection refused), and served its own 502 instead of Django's / -> /channels/ redirect — surfacing intermittently (most visibly over Tailscale) and masked by per-request retries, which made it look host- or cache-specific. Pin all three upstreams to 127.0.0.1. Verified live: zero new [::1] failures under load.
2026-06-17 Remove sensor data action log views TODO
2026-06-18 Enforce "one channel + pump at a time" for manual Test Channel taps
    The web "Test Channel" toggle drove watering GPIO directly through core/channel.setOutputState, bypassing the PumpController that owns the max_concurrent=1 guard. Because the API runs 3 gunicorn work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
    Make the core PumpController the single owner of watering GPIO. The API now enqueues a ManualCommand row instead of touching GPIO; the single core process drains pending commands each loop pass and r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
2026-06-18 Show version in web footer, sourced from globals/config.py
    The footer carried no version, and the only web version literal lived in the
    About dialog. Add a context processor (tethys_web.context_processors.app_version)
    that exposes str(config.version) as {{ tethys_version }} to every template, and
    render it in both the footer brand line and the About dialog. The web app now
    has no hardcoded version literal -- both spots track the release version from
    the single source of truth automatically.
2026-06-18 Add optional on-demand webcam tab (tethys-camera service)
    New isolated tethys-camera systemd service (stdlib ThreadingHTTPServer on
    127.0.0.1:8002, nginx-fronted at /camera/) serving authenticated JPEG
    snapshots, plus a Webcam tab in the web UI. Fail-closed, idle auto-off (15s),
    hard max-on ceiling (30 min); live-view only, nothing recorded.
    - camera/: config, V4L2 USB capture backend (capability-based device
    selection), on-demand snapshot controller, and the HTTP service with pure
    authorize()/route_request() so status codes are unit-tested without a socket.
    - web: Webcam tab (webcam.ts, index-webcam.html) plus nav/route/view wiring.
    - install: localize + enable tethys-camera and the /c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
    [config.py]
2026-06-18 Webcam: device-derived capture resolution + full-screen view
    The Webcam tab captured at a fixed 1280x720 and had no way to view the live
    frame full-screen. Resolution is now selectable from a dropdown the client
    fills from the camera itself (so it isn't tied to one model), and the frame
    can be expanded to fill the viewport -- both aimed at phone-width viewing.
    Both are in-session only; nothing is persisted or recorded, and capture stays
    one-shot (resolution is a per-request parameter, no device restart).
    - Selectable resolution: cameraController.status() now reports the camera's
    advertised MJPG sizes plus the default. V4l2UsbBackend.supported_resolutions()
    parses `v4l2-ctl --list-format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
2026-06-18 Core: run manual Test-Channel on a 1s thread; revive fan controller
    Manual activate/deactivate were drained once per main-loop pass, behind a 30s blocking radio-listen window, so taps took 5-30s to act. Drain the manual-command queue on its own ~1s daemon thread instead, independent of the radio window. The pump controller is already thread-safe (RLock + max_concurrent=1), so the one-channel power limit still holds across the manual and automatic paths.
    The same broken wiring meant the fan controller never ran: main() wrapped a synchronous while-loop in asyncio.create_task(), which blocked before the fan task was ever created (PWM never logged). Replace the asyncio model with plain daemon t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
    [fanController.py, tethys_core.py]
2026-06-18 Webcam: focus/zoom sliders read from the camera (+ keep-alive, frame counter)
    Focus/zoom offered as live sliders whose ranges are read from the camera
    (v4l2-ctl --list-ctrls, fail-soft); a slider is disabled for a control the
    camera doesn't expose, and a pick is remembered per-device. The snapshot
    request carries ?focus=&zoom= (range-validated -> 400) and is applied per grab.
    Manual focus is now actually honored. Two C200 quirks (verified on hardware):
    the camera resets focus_absolute when a stream stops, and its focus motor only
    travels while streaming. So a one-shot grab that kept the frame after 2 settle
    frames caught the lens mid-travel -> looked like autofocus "hunting". A focused
    grab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
    [config.py]
2026-06-18 Webcam: USB-drop auto-recovery (watchdog + Reset button)
    The Anker C200 occasionally EPROTO-crashes mid-session and disconnects;
    once it's off the bus only a USB host-controller re-enumeration brings it
    back (a service restart cannot). Recover it without a physical replug via
    two paths into globals/usb_recovery.py:
    - Watchdog auto-heal: tethys_watchdog checks the bus every minute and
    re-enumerates a missing camera, rate-limited by exponential back-off so
    a genuinely dead/unplugged camera isn't reset every minute.
    - User-triggered: key-gated POST /api/camera/reset-usb/ + a webcam-tab
    Reset button surfaced after repeated snapshot failures.
    Resilience hardening:
    - Cross-process flock ar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
    [config.py, urls.py, views.py]
2026-06-19 Charts: show per-channel action threshold on moisture graph; label both threshold lines
    Draw the channel's actionTriggerPercent as an amber dashed reference line
    on the moisture chart, mirroring the battery low-voltage line. Source the
    value from the channelSummary payload measurements.ts already fetches.
    Add a filtered legend so each threshold line is captioned ("Action
    threshold: N%" / "Low-battery threshold: 3.5 V"); the legend logic now
    lives in baseOptions behind a showThresholdLegend flag.
2026-06-24 Charts: mark watering-action times on the moisture graph
    Overlay each watering as a dotted vertical line at its interpolated
    start time, drawn by a small per-chart Chart.js plugin. The measurements
    page now also fetches /api/actionLog/{channel} and threads it into the
    chart; a legend-only "Watering" dataset gives the markers a swatch and
    a show/hide toggle. Actions outside the loaded reading window are
    skipped rather than clamped.
